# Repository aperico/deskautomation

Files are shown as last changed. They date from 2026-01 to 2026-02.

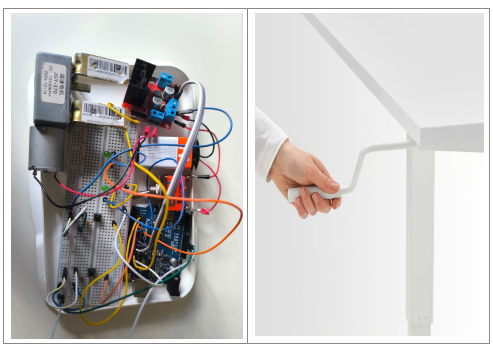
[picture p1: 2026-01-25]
00_training_context/resources/desk-arduino.png

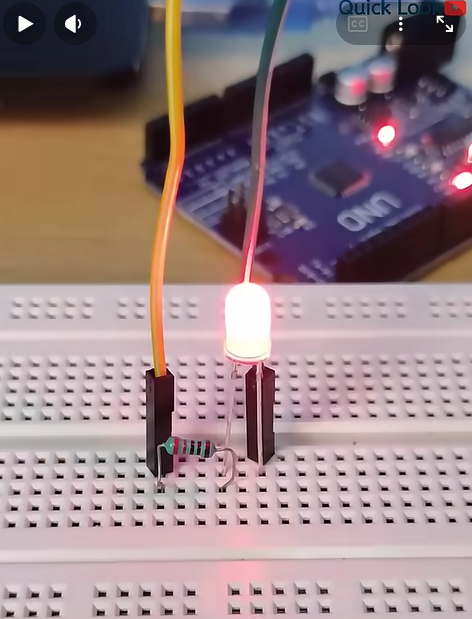
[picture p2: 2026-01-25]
00_training_context/resources/led-blink.png

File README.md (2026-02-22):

# Automated Mechanical Desk Lift System

## Quick Start

### Automated Development Pipeline (Recommended)

The fastest way to build and test the project:

```bash
# Complete pipeline: build + dual motor validation + static analysis
python toolchain/run-pipeline.py all

# Build only
python toolchain/run-pipeline.py clean-build

# Run tests (validates both MT_BASIC and MT_ROBUST motor types)
python toolchain/run-pipeline.py test

# Quick unit test during development
python toolchain/run-pipeline.py unit

# Get help
python toolchain/run-pipeline.py help
```

**📖 Detailed Instructions:**
- **Pipeline Guide:** [toolchain/README.md](toolchain/README.md) - Complete pipeline manual
- **Build Guide:** [src/README.md](src/README.md) - Manual build and test instructions
- **Test Overview:** [tests/README.md](tests/README.md) - Test suite quick reference

---

## Project Overview

The Automated Mechanical Desk Lift System is a motorized solution for height-adjustable desks, enabling users to easily switch between sitting and standing positions. The system features responsive controls, safety mechanisms to prevent accidents, and reliable operation over the product lifetime. Key features include:
- **Configurable motor drivers:** Support for both L298N (cost-optimized) and IBT_2 (high-capacity) motor controllers
- Motorized height adjustment from 30 cm to 120 cm
- Support for up to 20 kg load (monitor, keyboard, etc.)
- UP/DOWN buttons for intuitive control
- Immediate halt on button release or obstruction detection
- Robust safety features including limit sensors and current sensing for jam detection
- Smooth, predictable motion for user comfort
- Designed for office environments to improve health and productivity
- Modular architecture for maintainability and future feature expansion
- Comprehensive documentation and testing to ensure quality and reliability
- Open-source hardware and software design for community collaboration and innovation

### Motor Driver Options

The system supports two motor driver configurations, selectable at compile-time:

| Driver | Model | Cost | Capacity | Use Case |
|---|---|---|---|---|
| **MT_BASIC** | L298N Dual H-Bridge | Low (~$2-5) | Standard (~50kg) | Cost-optimized office desks |
| **MT_ROBUST** | IBT_2 Intelligent Driver | Moderate (~$10-15) | High (~100kg+) | Heavy-duty commercial desks |

Both drivers share the same software (unified HAL interface) and provide equivalent safety and functionality. See [Motor Driver Configuration Guide](documentation/07_MotorDriverConfiguration.md) for build and switching instructions.

## Motor Configuration Architecture

The system implements a robust motor configuration encapsulation pattern to support multiple motor driver types:

### Design Approach

- **Compile-Time Configuration (Current)**: Motor type is defined at compile-time in `src/motor_config.cpp` with validation
- **Runtime-Ready (Future)**: Architecture is prepared for NVM-based runtime configuration without code changes
- **Encapsulation Interface**: `MotorConfig_getMotorType()` function provides the sole accessor for motor configuration
- **Application Transparency**: All application logic is motor-type-agnostic; HAL layer handles driver-specific details

### Configuration Files

| File | Role | Details |
|---|---|---|
| `src/motor_config.h` | Public interface | Type definitions, feature documentation, function declaration |
| `src/motor_config.cpp` | Private implementation | MOTOR_TYPE macro, validation, getter function, NVM migration comments |

### Switching Motor Drivers

```bash
# Default: MT_BASIC (L298N)
cmake -S . -B build && cmake --build build

# To use MT_ROBUST (IBT_2): Edit src/motor_config.cpp line 44
# #define MOTOR_TYPE MT_BASIC        <- Change to MT_ROBUST
# Then rebuild:
cmake --build build
```

### Test Coverage

All 37 unit and integration tests validate both motor configurations:
- **MT_BASIC**: L298N driver (default)
- **MT_ROBUST**: IBT_2 driver

Tests can be run against either driver by changing the MOTOR_TYPE definition. See [05_SoftwareArchitecture.md](documentation/05_SoftwareArchitecture.md) (AD-009: Motor Configuration Encapsulation) and [06_00_DetailedDesign.md](documentation/06_00_DetailedDesign.md) (Motor Configuration Module) for detailed technical documentation.

---

## Documentation Index

### Development Guidelines

| Document | Description |
|---|---|
| [toolchain/coding_guides_and_checks.md](toolchain/coding_guides_and_checks.md) | **⚠️ Coding standards for safety-critical code (NASA Power of Ten, MISRA C:2012, ISO 25119)** |
| [toolchain/README.md](toolchain/README.md) | Development pipeline and automated testing guide |
| [toolchain/ARCHITECTURE.md](toolchain/ARCHITECTURE.md) | Pipeline architecture and design details |

### Requirements and Design

| Document | Description |
|---|---|
| [01_MissionStatement.md](documentation/01_MissionStatement.md) | Project mission and overall purpose |
| [01_SystemObjectives.md](documentation/01_SystemObjectives.md) | High-level system objectives and goals |
| [02_ConceptOfOperations.md](documentation/02_ConceptOfOperations.md) | Operational concept and use cases |
| [02_01_HARA-prep.md](documentation/02_01_HARA-prep.md) | HARA preparation (draft) |
| [02_02_HARA-complete.md](documentation/02_02_HARA-complete.md) | Hazard analysis and risk assessment (HARA) |
| [02_03_SafetyGoals.md](documentation/02_03_SafetyGoals.md) | Safety goals derived from HARA |
| [03_00_SystemRequirements.md](documentation/03_00_SystemRequirements.md) | System-level requirements specification |
| [03_01_SystemArchitecture.md](documentation/03_01_SystemArchitecture.md) | System architecture and interfaces |
| [03_01_01_TechnicalSafetyConcept.md](documentation/03_01_01_TechnicalSafetyConcept.md) | Technical safety concept |
| [03_02_RequirementsTraceabilityMatrix.md](documentation/03_02_RequirementsTraceabilityMatrix.md) | Requirements traceability matrix |
| [04_SoftwareRequirements.md](documentation/04_SoftwareRequirements.md) | Software requirements and functional specifications |
| [04_01_SoftwareVerificationSpecification.md](documentation/04_01_SoftwareVerificationSpecification.md) | Software test specifications and verification methods |
| [05_SoftwareArchitecture.md](documentation/05_SoftwareArchitecture.md) | Software architecture design and component structure |
| [06_00_DetailedDesign.md](documentation/06_00_DetailedDesign.md) | Detailed software design and implementation details |
| [06_01_DetailedDesign_InteractionDiagrams.md](documentation/06_01_DetailedDesign_InteractionDiagrams.md) | Sequence diagrams and data flow visualizations |
| [07_MotorDriverConfiguration.md](documentation/07_MotorDriverConfiguration.md) | Motor driver configuration guide (L298N vs IBT_2)
| [10_SystemTestSpecification.md](documentation/10_SystemTestSpecification.md) | System test plan and test specifications |
| [10_01_SystemTestReport.md](documentation/10_01_SystemTestReport.md) | System test report and results |
| [11_HardwareDocumentation.md](documentation/11_HardwareDocumentation.md) | Hardware components and wiring documentation |
| [02_ConceptOfOperations_Reviews.md](documentation/02_ConceptOfOperations_Reviews.md) | ConOps review protocol and records |
| [03_00_SystemRequirements_Reviews.md](documentation/03_00_SystemRequirements_Reviews.md) | System requirements review protocol and records |
| [03_01_01_TechnicalSafetyConcept_Reviews.md](documentation/03_01_01_TechnicalSafetyConcept_Reviews.md) | Technical safety concept review protocol and records |
| [03_01_SystemArchitecture_Reviews.md](documentation/03_01_SystemArchitecture_Reviews.md) | System architecture review protocol and records |
| [04_SoftwareRequirements_Reviews.md](documentation/04_SoftwareRequirements_Reviews.md) | Software requirements review protocol and records |
| [05_SoftwareArchitecture_Reviews.md](documentation/05_SoftwareArchitecture_Reviews.md) | Software architecture review protocol and records |
| [06_DetailedDesign_Reviews.md](documentation/06_DetailedDesign_Reviews.md) | Detailed design review protocol and records |
| [10_SystemTestSpecification_Reviews.md](documentation/10_SystemTestSpecification_Reviews.md) | System test specification review protocol and records |
| [feature-pdrs/](documentation/feature-pdrs/) | System feature concept reviews |

## Project Structure

### Root Directory

| File/Directory | Description |
|---|---|
| `CMakeLists.txt` | CMake build configuration file |
| `CMakePresets.json` | CMake preset configurations |
| `README.md` | Project overview and instructions (this file) |
| `.github/` | GitHub workflows and CI/CD configuration |

### Source Code (`src/`)

| File | Description |
|---|---|
| `desk_app.cpp/h` | Main application logic and state machine |
| `desk_types.h` | Type definitions and data structures |
| `hal.cpp/h` | Hardware Abstraction Layer (HAL) interface |
| `motor_config.h` | Motor driver type configuration (MT_BASIC or MT_ROBUST) |
| `motor_controller.cpp/h` | Motor control logic and algorithms |
| `pin_config.h` | Arduino pin assignments (configurable per motor type) |
| `src.ino` | Arduino firmware entry point |

### Tests (`tests/`)

| File | Description |
|---|---|
| `UnitTests.cpp` | Unit tests for individual functions and classes |
| `ComponentTests.cpp` | Component-level integration tests |
| `IntegrationTests.cpp` | Full system integration tests |
| `hal_mock/` | Mock implementations of HAL for testing on host |
| `└── HALMock.cpp/h` | Mock HAL implementation |
| `└── SerialMock.cpp/h` | Mock Serial communication for testing |

### Training Materials (`00_training_context/`)

| File | Description |
|---|---|
| `00_agenda.md` | Training overview and agenda |
| `01_hello-world.md` | Getting started guide |
| `02_aisetup.md` | AI/Copilot setup instructions |
| `03_prompting-techniques.md` | AI prompting best practices |
| `04_00_deskautomation-syseng.md` | Systems engineering overview |
| `04_01_00_system-definition.md` | System definition guide |
| `04_01_01_system-definition-architecture.md` | Architecture definition guide |
| `04_02_software-construction.md` | Software construction practices |
| `04_03_00_component-verification.md` | Component testing guide |
| `04_03_01_software_integration-verification.md` | Integration testing guide |
| `04_03_03_system-testing.md` | System testing guide |
| `05_traceability-matrix.md` | Requirements traceability |
| `06_workflow-pipelines.md` | CI/CD pipeline documentation |
| `07_process-assessment.md` | Process quality assessment |

### Schematics (`schematics/`)

| Directory | Description |
|---|---|
| `schmatics_desk_automation/` | KiCad project files for desk automation |
| `└── DeskAutomation_MotorControl/` | Motor control circuit schematics |
| `└── DeskAutomation.pretty/` | Custom KiCad footprints |

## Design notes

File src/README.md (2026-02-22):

# Source Code Build & Test Guide

This directory contains the source code for the Automated Mechanical Desk Lift System. For high-level project documentation and overview, see the [main README](../README.md).

## 🚀 Recommended: Automated Pipeline

**Use the automated development pipeline for the fastest and most reliable builds:**

```bash
# Complete pipeline: build + dual motor validation + static analysis
python toolchain/run-pipeline.py all

# Build only (clean + configure + build)
python toolchain/run-pipeline.py clean-build

# Run all tests (validates both MT_BASIC and MT_ROBUST motor types)
python toolchain/run-pipeline.py test

# Quick development workflow
python toolchain/run-pipeline.py unit        # Unit tests only
python toolchain/run-pipeline.py component   # Component tests only

# Get help
python toolchain/run-pipeline.py help
```

**Why use the pipeline?**
- ✅ Automated dual motor type validation (MT_BASIC + MT_ROBUST)
- ✅ Consistent build environment
- ✅ Comprehensive test coverage (37 tests)
- ✅ Static analysis integration
- ✅ Detailed results saved to `toolchain/results/`

**📖 Complete Pipeline Documentation:** [toolchain/README.md](../toolchain/README.md)

---

## Manual Build Instructions

For manual control or understanding the build process, use these commands:

### Prerequisites
- Windows with MSYS2 installed
- CMake
- MinGW-w64 toolchain (via MSYS2)
- C++17 compiler

### Build Commands (Command Line)

#### Clean Build Directory
```bash
Remove-Item -Path "build" -Recurse -Force -ErrorAction SilentlyContinue
```

Or using CMake:
```bash
cmake --build build --target clean
```

#### Configure
```bash
cmake -S . -B build
```

**With Motor Driver Selection:**
```bash
# Build for L298N (default)
cmake -S . -B build -DMOTOR_TYPE=MT_BASIC

# Build for IBT_2 (high-capacity)
cmake -S . -B build -DMOTOR_TYPE=MT_ROBUST
```

#### Build
```bash
cmake --build build --config Release
```

#### Full Build Sequence (Clean → Configure → Build)
```bash
Remove-Item -Path "build" -Recurse -Force -ErrorAction SilentlyContinue
cmake -S . -B build
cmake --build build --config Release
```

### Build Using VS Code Tasks

The project includes predefined VS Code tasks for building:

1. **CMake: Clean** - Removes the build directory
2. **CMake: Configure** - Configures the CMake project (depends on Clean)
3. **CMake: Build** - Builds the project (depends on Configure)

To run these tasks:
- Press `Ctrl+Shift+P` and type "Run Task"
- Select the desired task from the list
- Or use the Terminal menu → Run Task

The tasks automatically chain dependencies, so running "CMake: Build" will clean and configure first if needed.

### Build Artifacts

After a successful build, you'll find:
- `build/UnitTests.exe` - Unit test executable (6 tests)
- `build/ComponentTests.exe` - Component test executable (17 tests)
- `build/IntegrationTests.exe` - Integration test executable (14 tests)
- Build artifacts in `build/` directory

## Motor Driver Configuration

The system supports two motor driver configurations selected at compile-time:

| Driver | Model | Capacity | Use Case |
|---|---|---|---|
| **MT_BASIC** (default) | L298N Dual H-Bridge | Standard (~50kg) | Cost-optimized office desks |
| **MT_ROBUST** | IBT_2 Intelligent Driver | High (~100kg+) | Heavy-duty commercial desks |

Both drivers share the same software architecture and provide identical safety functionality through a unified Hardware Abstraction Layer (HAL).

### Selecting a Motor Driver

**Option 1: CMake Configuration (Recommended)**

When configuring the build, specify the motor type:

```bash
# Build for L298N (default) - cost-optimized
cmake -S . -B build -DMOTOR_TYPE=MT_BASIC
cmake --build build --config Release

# Build for IBT_2 - high-capacity
cmake -S . -B build -DMOTOR_TYPE=MT_ROBUST
cmake --build build --config Release
```

**Option 2: Edit motor_config.h**

Edit [motor_config.h](motor_config.h) line 47:

```cpp
// For L298N:
#define MOTOR_TYPE MT_BASIC      // Default

// For IBT_2:
#define MOTOR_TYPE MT_ROBUST
```

Then clean and rebuild:
```bash
Remove-Item -Path build -Recurse -Force
cmake -S . -B build
cmake --build build --config Release
```

### Verifying Motor Driver Type

After building, the active motor driver type is embedded in the binary. Pin assignments are determined by the selection:

**L298N (MT_BASIC):**
- PIN_MOTOR_EN1 = 6  (Enable UP direction)
- PIN_MOTOR_EN2 = 7  (Enable DOWN direction)
- PIN_MOTOR_PWM = 9  (Speed control)

**IBT_2 (MT_ROBUST):**
- PIN_MOTOR_LPWM = 9   (Left PWM - UP direction)
- PIN_MOTOR_RPWM = 10  (Right PWM - DOWN direction)
- PIN_MOTOR_CIN = A1   (Diagnostic input, optional)

See [Motor Driver Configuration Guide](../documentation/07_MotorDriverConfiguration.md) for detailed hardware setup instructions.

## Configuration

Safety-related thresholds and ADC conversion constants are defined in [safety_config.h](safety_config.h).

```cpp
static const uint16_t MOTOR_SENSE_THRESHOLD_MA = 150U;
static const uint16_t MOTOR_SENSE_OBSTRUCTION_THRESHOLD_MA = 200U;
static const uint32_t MOTOR_SENSE_FAULT_TIME_MS = 100U;
static const uint16_t ADC_REF_MV = 5000U;
static const uint16_t SHUNT_MILLIOHMS = 500U;
```

**Tuning guidance:**
- Measure motor current at idle STOP and normal motion with a meter.
- Set `MOTOR_SENSE_THRESHOLD_MA` above STOP current noise but below expected motion current.
- Set `MOTOR_SENSE_OBSTRUCTION_THRESHOLD_MA` to detect jam conditions during motion (typically 200 mA).
- Verify `MOTOR_SENSE_FAULT_TIME_MS` avoids false positives during brief transients.
- If you change the shunt resistor, update `SHUNT_MILLIOHMS` to keep current conversion accurate.

## Testing

### Building Tests

Tests are automatically built as part of the main build process. The CMake configuration includes all test files and links them with Google Test.

To build tests:
```bash
# Full build (includes tests)
cmake -S . -B build
cmake --build build --config Release
```

Or use the VS Code task: **CMake: Build**

### Test Executables

After building, the test executables are located at:
```
build/UnitTests.exe        - Unit tests (6 tests)
build/ComponentTests.exe   - Component tests (17 tests)
build/IntegrationTests.exe - Integration tests (14 tests)
Total: 37 tests
```

### Running Tests

#### Run All Tests

Using CTest (runs all test executables):
```bash
ctest --test-dir build -C Release --output-on-failure
```

Using test executables directly:
```bash
# Run all unit tests
./build/UnitTests.exe

# Run all component tests
./build/ComponentTests.exe

# Run all integration tests
./build/IntegrationTests.exe
```

Or use the VS Code task: **CTest: Run All**

#### Run Specific Tests

Run specific unit tests:
```bash
./build/UnitTests.exe --gtest_filter=MotorController.*
```

Run specific component tests:
```bash
./build/ComponentTests.exe --gtest_filter=TC_SWReq001
```

Run specific integration tests:
```bash
./build/IntegrationTests.exe --gtest_filter=HAL.*
```

Using CTest with regex filter:
```bash
ctest --test-dir build -C Release -R "^ComponentTests$" --output-on-failure
```

#### List Available Tests

```bash
# List unit tests
./build/UnitTests.exe --gtest_list_tests

# List component tests
./build/ComponentTests.exe --gtest_list_tests

# List integration tests
./build/IntegrationTests.exe --gtest_list_tests
```

### Test Types

The project includes three types of tests:

1. **Unit Tests** - Test individual functions and classes in isolation
2. **Component Tests** - Test integrated components (e.g., DeskController with mocked HAL)
3. **Integration Tests** - Test full system integration with hardware abstraction layer

All tests use Google Test framework and are located in the `tests/` directory.

### Test Filtering Options

Google Test supports various filtering patterns:
- `*` - Matches any string
- `?` - Matches any single character
- Use `:` to separate multiple patterns (OR logic)
- Prefix with `-` to exclude tests

Examples:
```bash
# Run all tests in a component test suite except one
./build/ComponentTests.exe --gtest_filter=-TC_SWReq001

# Run multiple specific unit tests
./build/UnitTests.exe --gtest_filter=MotorController.Initialize:MotorController.SetSpeed
```

## CI/CD Pipeline

### Local Development Pipeline

The `tests/toolchain/run-pipeline.py` script provides a convenient way for developers to execute common development tasks locally, including building, testing, and static analysis.

#### Prerequisites

- Python 3.7+
- MSYS2 with MinGW-w64 toolchain
- CMake
- cppcheck (for static analysis): `pacman -S mingw-w64-x86_64-cppcheck`

#### Usage

```bash
python tests/toolchain/run-pipeline.py <command>
```

#### Available Pipeline Commands

| Command | Description |
|---|---|
| `clean-build` | Clean build directory and build the project |
| `rebuild` | Full rebuild (clean + configure + build) |
| `test` | Run all test cases |
| `clean-test` | Clean, build, and run all test cases |
| `static-analysis` | Run static analysis using cppcheck |
| `all` | Run everything (rebuild + test + static analysis) |
| `help` | Show help message |

#### Pipeline Examples

**Clean and Build:**
```bash
python tests/toolchain/run-pipeline.py clean-build
```

**Rebuild Everything:**
```bash
python tests/toolchain/run-pipeline.py rebuild
```

**Run All Tests:**
```bash
python tests/toolchain/run-pipeline.py test
```

**Clean and Run All Tests:**
```bash
python tests/toolchain/run-pipeline.py clean-test
```

**Run Static Analysis:**
```bash
python tests/toolchain/run-pipeline.py static-analysis
```

**Run Complete Pipeline:**
```bash
python tests/toolchain/run-pipeline.py all
```

This will:
1. Clean the build directory
2. Configure CMake
3. Build the project
4. Run all tests
5. Run static analysis

#### Pipeline Output

The script provides color-coded output:
- 🟢 Green: Success messages
- 🔵 Cyan: Info messages
- 🔴 Red: Error messages
- 🟡 Yellow: Section headers

#### Pipeline Results Storage

All pipeline results are stored in the `tests/results/` directory:

| Result File | Description |
|---|---|
| `cmake_configure.txt` | CMake configuration output with warnings |
| `build_log.txt` | Complete build log with compiler warnings |
| `test_results.txt` | Test execution results with pass/fail summary |
| `static_analysis.txt` | Human-readable static analysis report |
| `static_analysis.xml` | Machine-readable XML for CI integration |

**Note:** Result files are overwritten on each pipeline run. Each file includes a header with:
- Full command executed
- Timestamp of execution
- Brief description of the results
- Relevant configuration details

These logs are useful for:
- Reviewing the latest build/test/analysis results
- Debugging compilation issues
- Quick access to compiler warnings and static analysis findings
- CI integration via XML output

#### Pipeline Exit Codes

- `0`: Success
- `1`: Failure (build, test, or analysis failed)

#### Local vs CI/CD

This script mirrors the CI/CD pipeline configured in `.github/workflows/`, allowing developers to validate their changes locally before pushing to the repository.

## Source Files

| File | Description |
|---|---|
| `desk_app.cpp/h` | Main application logic and state machine |
| `desk_types.h` | Type definitions and data structures |
| `hal.cpp/h` | Hardware Abstraction Layer (HAL) interface |
| `motor_controller.cpp/h` | Motor control logic and algorithms |
| `pin_config.h` | Arduino pin assignments and hardware configuration |
| `safety_config.h` | Safety thresholds and configuration constants |
| `src.ino` | Arduino firmware entry point |

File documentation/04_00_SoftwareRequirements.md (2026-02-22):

# Software Requirements

## Overview

This document defines functional software requirements derived from system requirements. These requirements specify **what** the software subsystem shall do, independent of hardware implementation. All requirements are designed to be unit-testable using mock hardware abstractions.

**Document Version:** 1.1  
**Date:** January 25, 2026  
**Status:** Updated

---

## Abstraction Layer

Software requirements are intentionally **hardware-independent**:

- ❌ No pin numbers or GPIO addresses
- ❌ No motor driver chip specifications
- ❌ No PWM frequency or duty cycle details
- ✅ Focus on software logic, timing, and state management
- ✅ Hardware abstraction layer (HAL) isolates physical interface

**Hardware dependencies are encapsulated in HAL**, which provides:
- `HAL_readButton(button_id)` → button state
- `HAL_readLimitSensor(sensor_id)` → sensor state
- `HAL_setMotor(direction, speed)` → motor control
- `HAL_getTime()` → system time in ms

## Requirements Characteristics

All software requirements comply with INCOSE quality criteria:

- ✅ **Necessary**: Each requirement addresses a distinct software function
- ✅ **Unambiguous**: Uses "shall" with quantitative acceptance criteria
- ✅ **Verifiable**: Unit test methods specified using mocks/stubs
- ✅ **Feasible**: All requirements implementable in embedded software
- ✅ **Traceable**: Clear links to parent system requirements
- ✅ **Software-focused**: Describes software behavior, not hardware implementation

## Traceability

**Derived from:**
- [03_00_SystemRequirements.md](03_00_SystemRequirements.md)

**Verification:**
- [04_01_SoftwareVerificationSpecification.md](04_01_SoftwareVerificationSpecification.md)

---

## Requirements Specification

| SWReq-ID | Statement | Rationale | Derives From |
|---|---|---|---|
| **SWReq-001** | The software subsystem shall detect UP button press within 100 ms and command motor activation in the upward direction. | Supports system responsiveness requirement (SysReq-002). Software input processing latency must be minimized to meet 1.0 sec total response budget. | SysReq-002 |
| **SWReq-002** | The software subsystem shall detect DOWN button press within 100 ms and command motor activation in the downward direction. | Supports system responsiveness requirement (SysReq-002). Software input processing latency must be minimized to meet 1.0 sec total response budget. | SysReq-002 |
| **SWReq-003** | The software subsystem shall detect button release within 50 ms and command motor deactivation. | Critical for meeting 500 ms halt requirement (SysReq-003). Software must respond faster than system-level budget to account for hardware response time. | SysReq-003 |
| **SWReq-004** | The software subsystem shall ignore motor activation commands when both UP and DOWN buttons are detected as pressed simultaneously. | Implements safety logic for conflicting inputs (SysReq-005). Prevents undefined motor behavior and potential hardware stress. | SysReq-005 |
| **SWReq-005** | The software subsystem shall command motor stop when upper limit sensor is active, even if UP button is pressed. | Enforces travel limit protection (SysReq-007). Software must override user input to protect mechanical system. | SysReq-007 |
| **SWReq-006** | The software subsystem shall command motor stop when lower limit sensor is active, even if DOWN button is pressed. | Enforces travel limit protection (SysReq-007). Software must override user input to protect mechanical system. | SysReq-007 |
| **SWReq-007** | The software subsystem shall maintain motor control state machine with at least three states: IDLE, MOVING_UP, and MOVING_DOWN. | Provides structured control logic for predictable behavior (SysReq-002, SysReq-003). State machine ensures unambiguous system response to all input combinations. | SysReq-002, SysReq-003 |
| **SWReq-008** | The software subsystem shall execute the main control loop with a cycle time of ≤ 50 ms. | Ensures timely input processing and output response to meet system timing requirements (SysReq-002, SysReq-003). Fast loop enables responsive button detection and motor commands. | SysReq-002, SysReq-003 |
| **SWReq-009** | The software subsystem shall debounce button inputs using a 20 ms debounce window. | Prevents false triggers from mechanical button bounce, ensuring reliable user intent detection (SysReq-002). Industry-standard debounce time for tactile switches. | SysReq-002 |
| **SWReq-010** | The software subsystem shall maintain operational state and command history for diagnostic purposes. | Supports reliability and maintainability goals (SysReq-008). Enables post-failure analysis and verification of state transitions during testing. | SysReq-008 |
| **SWReq-011** | The software subsystem shall implement a non-blocking scheduler that invokes `APP_Task()` at a fixed period of 250 ms (±10 ms). | Provides deterministic application-level timing while avoiding blocking calls in the main loop, enabling timely safety reactions and I/O servicing. | SysReq-009 |
| **SWReq-012** | The software subsystem shall command motor STOP when no valid UP/DOWN command is present. | Prevents unintended motion in the absence of user intent (SysReq-010). | SysReq-010 |
| **SWReq-013** | The software subsystem shall initialize to a safe STOP state after reset or brownout and require a new valid command before motion. | Prevents unintended motion on power recovery (SysReq-011). | SysReq-011 |
| **SWReq-014** | The software subsystem shall detect motor driver stuck-on or runaway behavior and enter a fault state that commands STOP and indicates error. | Mitigates electrical fault hazards (SysReq-012). | SysReq-012 |
| **SWReq-015** | The software subsystem shall support configurable motor driver implementation (MT_BASIC: L298N or MT_ROBUST: IBT_2) with identical functional behavior across both variants. | Enables product line support for multiple hardware configurations from unified codebase (SysReq-014). All control logic, safety features, and timing requirements shall be motor-type-agnostic; differences encapsulated in HAL. | SysReq-014 |

---

## Requirements Traceability Matrix

### Upstream Traceability (System → Software)

| System Requirement | Derived Software Requirements |
|---|---|
| SysReq-002: Response Time | SWReq-001, SWReq-002, SWReq-007, SWReq-008, SWReq-009 |
| SysReq-003: Motion Halt | SWReq-003, SWReq-007, SWReq-008 |
| SysReq-005: Conflicting Inputs | SWReq-004 |
| SysReq-007: Limit Protection | SWReq-005, SWReq-006 |
| SysReq-008: Reliability | SWReq-010 |
| SysReq-009: Scheduler Cadence | SWReq-011, SWReq-008 |
| SysReq-010: No Motion Without Valid Command | SWReq-012 |
| SysReq-011: Safe STOP After Reset/Brownout | SWReq-013 |
| SysReq-012: Stuck-On/Runaway Detection | SWReq-014 |
| SysReq-014: Motor Type Configuration | SWReq-015 |

---

## Test Strategy

All software verification specifications, test methods, test procedures, and test coverage requirements are defined in [04_01_SoftwareVerificationSpecification.md](04_01_SoftwareVerificationSpecification.md).

---

## Software Requirements Allocation

| Software Component | Allocated Requirements |
|---|---|
| Button Input Handler | SWReq-001, SWReq-002, SWReq-003, SWReq-009 |
| State Machine | SWReq-007, SWReq-010 |
| Safety Logic | SWReq-004, SWReq-005, SWReq-006, SWReq-012 |
| Control Loop Manager | SWReq-008 |
| Startup/Reset Handling | SWReq-013 |
| Fault Handling/Diagnostics | SWReq-014 |
| Motor Configuration Module | SWReq-015 |

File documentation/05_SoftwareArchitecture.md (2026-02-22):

# Software Architecture

## Overview

This document defines the software architecture for the Standing Desk Automation System. The architecture follows a layered design pattern with clear separation of concerns to enable testability, maintainability, and safety.

**Document Purpose and Detail Level**
- **Purpose:** Define the software structure, responsibilities, and interfaces needed to implement the system requirements.
- **Detail Level:** Software layers, modules, data flow, and state machine behavior; no system hardware decomposition.
- **Use:** Input to detailed design and test development; aligns with system architecture constraints.

**Document Version:** 1.0  
**Date:** January 24, 2026  
**Status:** Approved

---

## Traceability

**Derived from:**
- [03_00_SystemRequirements.md](03_00_SystemRequirements.md)
- [03_01_SystemArchitecture.md](03_01_SystemArchitecture.md)
- [04_SoftwareRequirements.md](04_SoftwareRequirements.md)

---

## Architectural Principles

1. **Testability**: Application logic is hardware-independent and unit-testable with mocks
2. **Simplicity**: Suitable for resource-constrained Arduino environment
3. **Safety**: State machine enforces safety rules and deterministic behavior
4. **Real-time**: Software design meets system-level timing constraints

---

## Timing and Safety Constraints

System-level timing and safety requirements are defined in the System Architecture and Technical Safety Concept. The software design implements these constraints via the control loop, state machine, and safety logic.

---

## Layer Architecture

```mermaid
graph TB
    subgraph "Layer 4: Main Loop / Signal Layer"
        Main[Main Loop<br/>arduino.ino]
    end
    
    subgraph "Layer 3: Application Layer"
        App[DeskApp<br/>DeskController.cpp/h]
    end
    
    subgraph "Layer 2: Hardware Abstraction Layer"
        HAL[HAL Module<br/>HAL.cpp/h]
    end
    
    subgraph "Layer 1: Hardware"
        HW[Physical Hardware<br/>GPIO, PWM, Timers]
    end
    
    Main -->|APP_Task| App
    App -->|Motor Commands| Main
    Main -->|HAL_read/write| HAL
    HAL -->|digitalWrite, analogWrite| HW
    
    style Main fill:#FFE6CC
    style App fill:#90EE90
    style HAL fill:#87CEEB
    style HW fill:#FFE6E6
```

### Layer 1: Hardware (External)

**Responsibility:** Provide physical inputs/outputs to the software via GPIO, PWM, and ADC signals.

**Description:** Hardware composition and wiring are defined at the system level; see System Architecture for component details.

---

### Layer 2: Hardware Abstraction Layer (HAL)

**Responsibility:** Encapsulate all hardware-specific code; provide hardware-independent API to upper layers.

**Files:** `HAL.h`, `HAL.cpp`, `PinConfig.h`

**Key Interfaces:** Hardware I/O functions for buttons, limits, motor, LEDs, and time services. Detailed signatures and data types are defined in the Detailed Design Specification.

**Description:** HAL is the only layer with direct access to Arduino libraries (digitalWrite, analogWrite, millis). Pin assignments and concrete data types are specified in the Detailed Design.

---

### Layer 3: Application Layer (DeskApp)

**Responsibility:** Implement desk control logic, state machine, and safety rules; hardware-agnostic.

**File:** `DeskController.h`, `DeskController.cpp`

**Description:** DeskApp contains the state machine and business logic. It is fully testable with mock inputs/outputs.

**Interfaces:** Function signatures and data structures are defined in the Detailed Design Specification.

---

### Layer 4: Main Loop / Signal Layer

**Responsibility:** Poll hardware via HAL, populate input structure, call APP_Task, execute output commands.

**File:** `arduino.ino`

**Description:** Main loop orchestrates I/O coordination and schedules the application task. Implementation details are specified in the Detailed Design.

---

## Motor Driver Abstraction

### Supported Drivers

The software architecture supports multiple motor driver implementations transparent to application logic:

| Driver | Model | Capabilities | Status |
|---|---|---|---|
| **MT_BASIC** | L298N Dual H-Bridge | Standard H-bridge with PWM speed control | ✅ Supported |
| **MT_ROBUST** | IBT_2 Dual H-Bridge (FET) | Enhanced H-bridge with better thermal characteristics | ✅ Supported |

### Abstraction Strategy

**Motor-Type-Agnostic Application Logic:**
- Application layer (`DeskApp`) makes no assumptions about hardware capabilities
- All control logic, safety features, and timing constraints are identical for both drivers
- Motor type influences only HAL implementation details, not functional behavior

**HAL Motor Control Interface:**
```
HAL_setMotor(direction, speed)  // Same interface for both drivers
├── MT_BASIC: Drives L298N GPIO pins (standard H-bridge)
└── MT_ROBUST: Drives IBT_2 GPIO pins (enhanced FET driver)
```

**Current Sensing Abstraction:**
```
current_ma = HAL_readMotorCurrent()  // Same interface for both drivers
├── MT_BASIC: Always returns 0 (no current sensor in hardware)
└── MT_ROBUST: Returns actual current from sense resistor
```

### Configuration Selection

Motor type is selected at compile-time via `motor_config.cpp`:
```cpp
#define MOTOR_TYPE MT_BASIC  // Change to MT_ROBUST for IBT_2 driver
```

All 37 unit and integration tests verify identical behavior across both configurations:
- Tests execute with default MT_BASIC configuration
- Can be recompiled with `TEST_MOTOR_TYPE=MT_ROBUST` to validate IBT_2 without code changes
- Both configurations pass all verification specifications without functional differences

---

## State Machine Design

### State Diagram

```mermaid
stateDiagram-v2
    [*] --> IDLE: Power On / APP_Init()
    
    IDLE --> MOVING_UP: UP pressed AND NOT upper_limit
    IDLE --> MOVING_DOWN: DOWN pressed AND NOT lower_limit
    IDLE --> IDLE: Both buttons pressed (conflicting input)
    
    MOVING_UP --> IDLE: UP released
    MOVING_UP --> IDLE: upper_limit reached
    MOVING_UP --> FAULT: Unexpected error
    
    MOVING_DOWN --> IDLE: DOWN released
    MOVING_DOWN --> IDLE: lower_limit reached
    MOVING_DOWN --> FAULT: Unexpected error
    
    FAULT --> IDLE: Fault cleared (power cycle)
    
    note right of IDLE
        Motor: STOP
        LED: IDLE (steady green)
    end note
    
    note right of MOVING_UP
        Motor: UP (speed 255)
        LED: ACTIVE (blinking)
    end note
    
    note right of MOVING_DOWN
        Motor: DOWN (speed 255)
        LED: ACTIVE (blinking)
    end note
    
    note right of FAULT
        Motor: STOP
        LED: ERROR (steady red)
    end note
```

### State Transition Table

| Current State | Input Condition | Next State | Motor Command | LED Status |
|---|---|---|---|---|
| IDLE | UP pressed AND NOT upper_limit | MOVING_UP | UP, speed=255 | ACTIVE |
| IDLE | DOWN pressed AND NOT lower_limit | MOVING_DOWN | DOWN, speed=255 | ACTIVE |
| IDLE | Both buttons pressed | IDLE | STOP | IDLE |
| IDLE | No buttons pressed | IDLE | STOP | IDLE |
| MOVING_UP | UP still pressed AND NOT upper_limit | MOVING_UP | UP, speed=255 | ACTIVE |
| MOVING_UP | UP released | IDLE | STOP | IDLE |
| MOVING_UP | upper_limit reached | IDLE | STOP | IDLE |
| MOVING_DOWN | DOWN still pressed AND NOT lower_limit | MOVING_DOWN | DOWN, speed=255 | ACTIVE |
| MOVING_DOWN | DOWN released | IDLE | STOP | IDLE |
| MOVING_DOWN | lower_limit reached | IDLE | STOP | IDLE |
| Any State | Unexpected error | FAULT | STOP | ERROR |

### State Entry/Exit Actions

**IDLE State:**
- **Entry:** Motor STOP, LED IDLE
- **In-State:** Monitor button inputs
- **Exit:** None

**MOVING_UP State:**
- **Entry:** Motor UP (speed=255), LED ACTIVE
- **In-State:** Monitor button release and upper limit
- **Exit:** Motor STOP

**MOVING_DOWN State:**
- **Entry:** Motor DOWN (speed=255), LED ACTIVE
- **In-State:** Monitor button release and lower limit
- **Exit:** Motor STOP

**FAULT State:**
- **Entry:** Motor STOP, LED ERROR, log fault
- **In-State:** System halted
- **Exit:** Requires power cycle to clear

---

## Interaction Diagrams

Interaction sequences and data flow diagrams are maintained in the Detailed Design Specification to keep implementation-level behavior in a single location.

---

## Requirements Traceability Matrix

### System Requirements → Architecture Elements

| System Req | Software Req | Architecture Element | Layer | Verification |
|---|---|---|---|---|
| SysReq-001 | SWReq-005, SWReq-006 | Limit sensor input + Safety logic | APP, HAL | Unit test with mock sensors |
| SysReq-002 | SWReq-001, SWReq-002, SWReq-008 | Button input handler + State transitions | APP, HAL | Timing test with mock GPIO |
| SysReq-003 | SWReq-003 | Button release detection + Motor stop | APP, HAL | Unit test with mock timer |
| SysReq-004 | SWReq-008 | Control loop timing (≤50ms cycle) | Main Loop | Loop timing measurement |
| SysReq-005 | SWReq-004 | Conflicting input detection | APP | Unit test with both buttons |
| SysReq-006 | — | Motor speed control (constant 255) | HAL | (Future: PWM ramping) |
| SysReq-007 | SWReq-005, SWReq-006 | Limit override logic | APP | Unit test with limit active |
| SysReq-008 | SWReq-010 | State transition logging | APP | Diagnostic log verification |

### Software Requirements → Architecture Functions

| Software Req | Function/Module | API | Layer |
|---|---|-----|---|
| SWReq-001 | Button UP handler | `HAL_readButton(BUTTON_UP)` | HAL |
| SWReq-002 | Button DOWN handler | `HAL_readButton(BUTTON_DOWN)` | HAL |
| SWReq-003 | Button release handler | `HAL_readButton()` + debounce | HAL |
| SWReq-004 | Conflicting input check | Safety logic in `APP_Task()` | APP |
| SWReq-005 | Upper limit check | `HAL_readLimitSensor(LIMIT_UPPER)` | HAL |
| SWReq-006 | Lower limit check | `HAL_readLimitSensor(LIMIT_LOWER)` | HAL |
| SWReq-007 | State machine | `APP_Task()` state transitions | APP |
| SWReq-008 | Control loop | `loop()` execution | Main |
| SWReq-009 | Debouncing | `HAL_readButton()` internal logic | HAL |
| SWReq-010 | Diagnostics | `APP_GetState()`, state log | APP |

---

## Interface Specifications

Detailed interface definitions, pin assignments, and timing budgets are specified in the Detailed Design Specification.

## Architectural Decisions

### AD-001: Layered Architecture
**Decision:** Use 4-layer architecture (Hardware, HAL, APP, Main Loop).  
**Rationale:** Enables unit testing of application logic without hardware; supports future platform portability.  
**Traceability:** All software requirements (SWReq-001 through SWReq-010).

### AD-002: State Machine Pattern
**Decision:** Implement control logic as explicit state machine with 4 states.  
**Rationale:** Provides deterministic, verifiable behavior; simplifies safety analysis.  
**Traceability:** SWReq-007, SysReq-002, SysReq-003.

### AD-003: Input/Output Structures
**Decision:** Use C structures for APP_Task interface instead of individual parameters.  
**Rationale:** Simplifies unit testing; easier to extend with new signals; clear API boundary.  
**Traceability:** SWReq-001 through SWReq-006.

### AD-004: HAL Owns All Hardware Access
**Decision:** Only HAL layer calls Arduino functions (digitalWrite, analogWrite, millis).  
**Rationale:** Enables mock-based testing; single point for hardware dependencies.  
**Traceability:** All software requirements.

### AD-005: Constant Motor Speed (No Ramping)
**Decision:** Motor speed fixed at 255 (full speed); no acceleration/deceleration profile.  
**Rationale:** Simplifies initial implementation; meets system requirements; ramping can be added later.  
**Traceability:** SysReq-004, SysReq-006.

### AD-006: Debouncing in HAL
**Decision:** Button debouncing implemented inside HAL_readButton().  
**Rationale:** Isolates timing complexity from APP layer; reusable across projects.  
**Traceability:** SWReq-009.

### AD-007: Limit Sensors Override Buttons
**Decision:** Limit sensors take priority over button inputs in safety logic.  
**Rationale:** Prevents mechanical over-travel; safety-critical requirement.  
**Traceability:** SysReq-007, SWReq-005, SWReq-006.

### AD-008: Non-Blocking Main Loop with Time-Based Scheduler
**Decision:** Main loop is non-blocking and executes application control logic at 4 Hz (every 250 ms).  
**Rationale:** 
- Prevents blocking delays that can impair safety-critical button response
- 4 Hz scheduler provides predictable timing for application task invocation
- Arduino loop() is called frequently; explicit timing check prevents excessive application task calls
- Allows I/O operations (HAL calls) to complete without waiting
**Traceability:** Foundational to responsive button handling (SysReq-002: ≤1 sec response) and halt timing (SysReq-003: ≤500 ms halt).

### AD-009: Motor Configuration Encapsulation
**Decision:** Motor type configuration is encapsulated via `MotorConfig_getMotorType()` getter function; direct application code shall not use the `MOTOR_TYPE` macro.

**Rationale:** 
- **Abstraction:** Hides motor type definition details from application code
- **Testability:** Enables testing both motor configurations (MT_BASIC and MT_ROBUST) without recompilation via `TEST_MOTOR_TYPE` override
- **Future NVM Support:** Architecture is prepared for runtime motor configuration via non-volatile memory without requiring header changes
- **Safety:** Centralized control of motor type configuration reduces risk of inconsistent usage across codebase
- **Maintenance:** Single point of definition for motor type handling simplifies future hardware variants

**Current Implementation:** Compile-time configuration (default: MT_BASIC/L298N). MOTOR_TYPE macro is defined and validated in `motor_config.cpp`.

**Future Implementation:** Will read motor type from NVM at runtime, enabling hardware auto-detection and multi-configuration support without recompilation.

**Verification:** 
- Application code uses `inputs->motor_type` from AppInput struct (populated via `MotorConfig_getMotorType()`)
- HAL layer uses runtime `g_motor_type` variable (set via `HAL_setMotorType()`)
- All 37 unit and integration tests validate both MT_BASIC and MT_ROBUST configurations

**Traceability:** All software requirements (SWReq-001 through SWReq-014); ensures motor-type-agnostic application logic.

---

## Design Constraints

1. **Memory:** Arduino UNO has 2 KB SRAM; minimize global variables
2. **Timing:** 
    - Meet system-level response and halt timing constraints
    - No blocking delays in main loop; utilize non-blocking scheduler (see AD-008)
3. **Safety:** All motor commands must be fail-safe (default to STOP)
4. **Testability:** APP layer must be testable without Arduino hardware

---

## Future Enhancements (Out of Scope)

- **Runtime Motor Configuration (In Progress):** Migrate from compile-time `MOTOR_TYPE` macro to NVM-based runtime configuration, enabling hardware auto-detection without recompilation (see AD-009: Motor Configuration Encapsulation for architecture readiness)
- PWM ramping for smooth acceleration/deceleration
- Position sensing and closed-loop control
- EEPROM storage for height presets
- Serial command interface for diagnostics
- Watchdog timer for fault detection

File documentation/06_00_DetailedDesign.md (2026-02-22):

# Detailed Design Specification

## Overview

This document provides implementation-level design details for the Standing Desk Automation System. It specifies data structures, algorithms, function interfaces, timing constraints, and error handling logic required for code implementation.

---

## Traceability

**Derived from:**
- [05_SoftwareArchitecture.md](05_SoftwareArchitecture.md)
- [04_SoftwareRequirements.md](04_SoftwareRequirements.md)
- [03_00_SystemRequirements.md](03_00_SystemRequirements.md)

**Related Documents:**
- [06_01_InteractionDiagrams.md](06_01_InteractionDiagrams.md) - Sequence diagrams and data flow visualizations

---

## Document Purpose

This detailed design bridges the gap between architecture and implementation. Developers can write code directly from this specification without requiring clarification on:
- Exact data structure layouts and field types
- Algorithm implementations (debouncing, state transitions)
- Function signatures with complete parameter specifications
- Timing constraints and performance requirements
- Error handling and edge case logic

**Document Version:** 1.0  
**Date:** January 24, 2026  
**Status:** Ready for Implementation

---

## Module Structure

```mermaid
classDiagram
    class PinConfig {
        <<configuration>>
        +PIN_BUTTON_UP: uint8_t
        +PIN_BUTTON_DOWN: uint8_t
        +PIN_LIMIT_UPPER: uint8_t
        +PIN_LIMIT_LOWER: uint8_t
        +PIN_MOTOR_EN1: uint8_t
        +PIN_MOTOR_EN2: uint8_t
        +PIN_MOTOR_PWM: uint8_t
        +PIN_MOTOR_SENSE: uint8_t
        +PIN_LED_BT_UP: uint8_t
        +PIN_LED_BT_DOWN: uint8_t
        +PIN_LED_ERROR: uint8_t
    }
    
    class HAL {
        -debounce_state[]: uint32_t
        -last_button_time[]: uint32_t
        +HAL_init() void
        +HAL_readButton(ButtonID) bool
        +HAL_readLimitSensor(LimitID) bool
        +HAL_readMotorCurrent() uint16_t
        +HAL_setMotor(MotorDirection, uint8_t) void
        +HAL_setLED(LEDStatus) void
        +HAL_getTime() uint32_t
    }
    
    class DeskApp {
        -current_state: AppState_t
        -state_entry_time: uint32_t
        -transition_count: uint32_t
        +APP_Init() void
        +APP_Task(AppInput_t*, AppOutput_t*) void
        +APP_GetState() AppState_t
        -processState(AppInput_t*, AppOutput_t*) void
        -transitionTo(AppState_t) void
    }
    
    class MainLoop {
        +setup() void
        +loop() void
        -readInputs(AppInput_t*) void
        -executeOutputs(AppOutput_t*) void
    }
    
    MainLoop --> DeskApp : calls APP_Task()
    MainLoop --> HAL : calls HAL functions
    DeskApp ..> AppInput_t : uses
    DeskApp ..> AppOutput_t : produces
    HAL ..> PinConfig : uses
```

---

## Interaction Diagrams and Data Flow

Detailed sequence diagrams and data flow visualizations are provided in the standalone document [06_01_InteractionDiagrams.md](06_01_InteractionDiagrams.md). This includes:

- **Sequence 1:** Normal Desk Raise (SysReq-002, SysReq-004)
- **Sequence 2:** Emergency Halt via Button Release (SysReq-003)
- **Sequence 3:** Conflicting Button Inputs (SysReq-005, SWReq-004)
- **Sequence 4:** Upper Limit Protection (SysReq-007, SWReq-005)
- **Sequence 5:** Full System Initialization (SysReq-001, SWReq-007)
- **Data Flow Diagram:** Module interactions and data structure flow

See [06_01_InteractionDiagrams.md](06_01_InteractionDiagrams.md) for complete descriptions and timing analysis.

---

## Motor Configuration Module

### Module Purpose

The Motor Configuration module (`motor_config.h`/`.cpp`) encapsulates motor driver type selection and provides a unified interface for the rest of the software to remain motor-type-agnostic. This ensures both MT_BASIC (L298N) and MT_ROBUST (IBT_2) can be supported identically without code duplication.

### Module Interface

```cpp
/// Get the current motor driver type
/// @return MotorType_t - MT_BASIC (0u) or MT_ROBUST (1u)
MotorType_t MotorConfig_getMotorType(void);
```

### Configuration Selection

Motor type is selected via compile-time definition in `src/motor_config.cpp`:

```cpp
#define MOTOR_TYPE MT_BASIC  // Change to MT_ROBUST to use IBT_2 driver
```

When changed, rebuild required: `cmake --build build`

### Implementation Details

- **Header File** (`motor_config.h`): Contains only public interface and type definitions
  - `MotorType_t` enum (MT_BASIC=0u, MT_ROBUST=1u)
  - `MotorConfig_getMotorType()` function declaration
  - Feature comparison documentation for both drivers

- **Implementation File** (`motor_config.cpp`): Contains configuration details
  - `MOTOR_TYPE` macro definition (compile-time value)
  - Compile-time validation checks (#error on invalid values)
  - `MotorConfig_getMotorType()` implementation
  - `TEST_MOTOR_TYPE` support for test-time overrides

### Test Compatibility

The module supports dual-configuration testing:
1. **Default Build**: Compiles with MT_BASIC, all 37 tests pass on MT_BASIC
2. **Alternative Build**: Can be recompiled with `-DTEST_MOTOR_TYPE=MT_ROBUST` to validate MT_ROBUST config without code changes

All application-level tests verify identical behavior across both motor types, ensuring the motor abstraction is transparent to the rest of the system.

### Traceability

- **System Requirement**: SysReq-014 (Motor driver support)
- **Software Requirement**: SWReq-015 (Motor type configuration abstraction)
- **Architecture Decision**: AD-009 (Motor Configuration Encapsulation)

### Future Enhancement: Runtime NVM Support

The current module is designed for easy migration to runtime motor configuration:
- To enable NVM-based motor type detection, only the `motor_config.cpp` implementation needs to change
- No header changes required when adding NVM support
- All application code remains unchanged

---

## Data Structure Definitions

### 1. Enumerated Types

```cpp
// Button identifiers
typedef enum {
    BUTTON_UP = 0,
    BUTTON_DOWN = 1,
    BUTTON_COUNT = 2
} ButtonID;

// Limit sensor identifiers
typedef enum {
    LIMIT_UPPER = 0,
    LIMIT_LOWER = 1,
    LIMIT_COUNT = 2
} LimitID;

// Motor direction commands
typedef enum {
    MOTOR_STOP = 0,
    MOTOR_UP = 1,
    MOTOR_DOWN = 2
} MotorDirection;

// LED status indicators
typedef enum {
    LED_OFF = 0,      // All LEDs off
    LED_IDLE = 1,     // Steady green (system ready)
    LED_ACTIVE = 2,   // Blinking green (motion in progress)
    LED_ERROR = 3     // Steady red (fault state)
} LEDStatus;

// Application states
typedef enum {
    APP_STATE_IDLE = 0,
    APP_STATE_MOVING_UP = 1,
    APP_STATE_MOVING_DOWN = 2,
    APP_STATE_FAULT = 3,
    APP_STATE_COUNT = 4
} AppState_t;
```

### 2. Input/Output Structures

```cpp
// Application input structure (from Main Loop → APP)
typedef struct {
    bool button_up;          // True if UP button currently pressed (debounced)
    bool button_down;        // True if DOWN button currently pressed (debounced)
    bool limit_upper;        // True if upper limit sensor active
    bool limit_lower;        // True if lower limit sensor active
    uint16_t motor_current_ma; // Motor current in mA (from current sense)
    uint32_t timestamp_ms;   // Current system time in milliseconds
} AppInput_t;

// Application output structure (from APP → Main Loop)
typedef struct {
    MotorDirection motor_cmd;    // Motor command: STOP/UP/DOWN
    uint8_t motor_speed;         // Motor PWM duty cycle: 0-255
    LEDStatus led_status;        // LED status indicator
    bool diagnostics_enabled;    // Enable diagnostic output (future)
} AppOutput_t;
```

### 3. Internal State Variables (DeskApp Module)

```cpp
// State machine variables (file-scope static in DeskApp.cpp)
static AppState_t current_state = APP_STATE_IDLE;
static uint32_t state_entry_time = 0;      // Time when current state was entered
static uint32_t state_transition_count = 0; // Total number of state transitions

// Diagnostic log (optional, for SWReq-010)
#define MAX_STATE_LOG 10
static struct {
    AppState_t state;
    uint32_t timestamp;
} state_log[MAX_STATE_LOG];
static uint8_t state_log_index = 0;
```

### 4. Debouncing Variables (HAL Module)

```cpp
// Debouncing state (file-scope static in HAL.cpp)
#define DEBOUNCE_TIME_MS 20
static uint32_t last_button_time[BUTTON_COUNT] = {0, 0};
static bool button_stable_state[BUTTON_COUNT] = {false, false};
static bool button_raw_state[BUTTON_COUNT] = {false, false};
```

### 5. Motor Current Sense Parameters

Motor current sense parameters are defined in [src/safety_config.h](../src/safety_config.h):

```cpp
// Motor current sense (safety monitoring)
static const uint16_t MOTOR_SENSE_THRESHOLD_MA = 150U;  // Stuck-on threshold (FSR-006 → SysReq-012)
static const uint16_t MOTOR_SENSE_OBSTRUCTION_THRESHOLD_MA = 200U;  // Obstruction during motion (FSR-007 → SysReq-013)
static const uint32_t MOTOR_SENSE_FAULT_TIME_MS = 100U;  // Time to confirm fault condition
static const uint16_t ADC_REF_MV = 5000U;
static const uint16_t SHUNT_MILLIOHMS = 500U;
```

**Notes:**
- `MOTOR_SENSE_THRESHOLD_MA` (150 mA): Maximum allowed current when motor is commanded STOP (stuck-on detection).
- `MOTOR_SENSE_OBSTRUCTION_THRESHOLD_MA` (200 mA): Abnormal current threshold during active motion (jam/obstruction detection).
- `MOTOR_SENSE_FAULT_TIME_MS` (100 ms): Confirmation window before transitioning to FAULT state (allows system to halt within 500 ms total per SysReq-013).
- Values are initial safety targets and must be tuned after hardware characterization with actual motor and load profile.
- **Traceability:**
  - Stuck-on → FSR-006 → SysReq-012 → SG-005
  - Obstruction → FSR-007 → SysReq-013 → SG-002

---

## Algorithm Specifications

### Algorithm 1: Button Debouncing (HAL Module)

**Purpose:** Filter mechanical button bounce to provide stable button state to application.

**Requirements:** SWReq-009 (20 ms debounce window)

**Pseudocode:**

```
FUNCTION HAL_readButton(button_id):
    current_time = millis()
    raw_state = digitalRead(button_pin[button_id]) == LOW  // Active low with pull-up
    
    IF raw_state != button_raw_state[button_id]:
        // Button state changed, start debounce timer
        button_raw_state[button_id] = raw_state
        last_button_time[button_id] = current_time
    
    // Check if debounce time has elapsed
    elapsed = current_time - last_button_time[button_id]
    IF elapsed >= DEBOUNCE_TIME_MS:
        // Stable state confirmed
        button_stable_state[button_id] = button_raw_state[button_id]
    
    RETURN button_stable_state[button_id]
END FUNCTION
```

**Timing Diagram:**

```
Button Physical State:  ___╱‾‾╲_╱‾‾‾‾‾‾‾‾‾‾‾‾‾‾‾‾‾‾‾‾‾
                           ^bounce period  ^stable
Raw Reading:           ___╱‾‾╲_╱‾‾‾‾‾‾‾‾‾‾‾‾‾‾‾‾‾‾‾‾‾
Time:                  0ms  5  10 15   20  25  30  35
Debounced Output:      ____________________╱‾‾‾‾‾‾‾‾‾
                                           ^20ms threshold
```

**Edge Cases:**
- Rapid button presses < 20 ms apart: Only last stable state is registered
- Button held during init: Starts debounced (safe)
- Simultaneous press/release: Each button debounced independently

---

### Algorithm 2: State Transition Logic (DeskApp Module)

**Purpose:** Implement state machine transitions based on inputs and current state.

**Requirements:** SWReq-007 (state machine with IDLE, MOVING_UP, MOVING_DOWN states)

**Pseudocode:**

```
FUNCTION APP_Task(inputs, outputs):
    // Process state-specific logic
    SWITCH current_state:
        CASE APP_STATE_IDLE:
            outputs.motor_cmd = MOTOR_STOP
            outputs.motor_speed = 0
            outputs.led_status = LED_IDLE
            
            // Check for transition to MOVING_UP
            IF inputs.button_up AND NOT inputs.button_down:
                IF NOT inputs.limit_upper:
                    transitionTo(APP_STATE_MOVING_UP)
            
            // Check for transition to MOVING_DOWN
            ELSE IF inputs.button_down AND NOT inputs.button_up:
                IF NOT inputs.limit_lower:
                    transitionTo(APP_STATE_MOVING_DOWN)
            
            // Conflicting inputs: stay in IDLE (SWReq-004)
            ELSE IF inputs.button_up AND inputs.button_down:
                // Ignore command, remain in IDLE
                outputs.motor_cmd = MOTOR_STOP
        
        CASE APP_STATE_MOVING_UP:
            outputs.motor_cmd = MOTOR_UP
            outputs.motor_speed = 255
            outputs.led_status = LED_ACTIVE
            
            // Check for return to IDLE
            IF NOT inputs.button_up:
                transitionTo(APP_STATE_IDLE)
            ELSE IF inputs.limit_upper:  // SWReq-005
                transitionTo(APP_STATE_IDLE)
        
        CASE APP_STATE_MOVING_DOWN:
            outputs.motor_cmd = MOTOR_DOWN
            outputs.motor_speed = 255
            outputs.led_status = LED_ACTIVE
            
            // Check for return to IDLE
            IF NOT inputs.button_down:
                transitionTo(APP_STATE_IDLE)
            ELSE IF inputs.limit_lower:  // SWReq-006
                transitionTo(APP_STATE_IDLE)
        
        CASE APP_STATE_FAULT:
            outputs.motor_cmd = MOTOR_STOP
            outputs.motor_speed = 0
            outputs.led_status = LED_ERROR
            // Requires power cycle to clear (future: add reset mechanism)
END FUNCTION

FUNCTION transitionTo(new_state):
    // Log transition for diagnostics (SWReq-010)
    state_log[state_log_index].state = new_state
    state_log[state_log_index].timestamp = HAL_getTime()
    state_log_index = (state_log_index + 1) % MAX_STATE_LOG
    
    // Update state variables
    current_state = new_state
    state_entry_time = HAL_getTime()
    state_transition_count++
END FUNCTION
```

---

### Algorithm 3: Motor Current Fault Detection (DeskApp Module)

**Purpose:** Detect motor faults: (a) stuck-on/runaway behavior while STOP commanded (FSR-006), and (b) obstruction/jam during motion (FSR-007).

**Requirements:** FSR-006, FSR-007, SysReq-012, SysReq-013, SWReq-014

**Fault Detection Cases:**

1. **Stuck-On Detection (FSR-006, SysReq-012)**: Motor command STOP but current remains high
2. **Obstruction Detection (FSR-007, SysReq-013)**: Motor commanded to move but current exceeds threshold (indicates jam or abnormal resistance)

**Pseudocode:**

```
FUNCTION check_motor_current_fault(inputs, outputs):
    // Case 1: Stuck-on detection (motor should be off but current is high)
    IF outputs.motor_cmd == MOTOR_STOP:
        IF inputs.motor_current_ma > MOTOR_SENSE_THRESHOLD_MA:
            IF fault_timer_ms == 0:
                fault_timer_ms = inputs.timestamp_ms
            ELSE IF (inputs.timestamp_ms - fault_timer_ms) >= MOTOR_SENSE_FAULT_TIME_MS:
                transitionTo(APP_STATE_FAULT)
        ELSE:
            fault_timer_ms = 0
    
    // Case 2: Obstruction detection (motor moving but current exceeds threshold)
    ELSE IF outputs.motor_cmd != MOTOR_STOP:
        IF inputs.motor_current_ma > MOTOR_SENSE_OBSTRUCTION_THRESHOLD_MA:
            IF obstruction_timer_ms == 0:
                obstruction_timer_ms = inputs.timestamp_ms
            ELSE IF (inputs.timestamp_ms - obstruction_timer_ms) >= MOTOR_SENSE_FAULT_TIME_MS:
                // Halt within 500 ms as per SysReq-013 & FSR-007
                transitionTo(APP_STATE_FAULT)
        ELSE:
            obstruction_timer_ms = 0
    ELSE:
        fault_timer_ms = 0
        obstruction_timer_ms = 0
END FUNCTION
```

**Notes:**
- `fault_timer_ms` and `obstruction_timer_ms` are static variables initialized to 0.
- The check runs once per control loop cycle after outputs are computed.
- Both thresholds are defined in [src/safety_config.h](../src/safety_config.h).
- Obstruction threshold likely > stuck-on threshold to account for normal loaded motion.

---

### Algorithm 4: Motor Control (HAL Module)

**Purpose:** Translate motor commands into hardware signals for L298N dual H-bridge motor driver.

**Requirements:** SysReq-002 (response ≤ 1 sec), SysReq-003 (halt ≤ 500 ms)

**L298N Motor Driver Control:**

| Direction | RPWM (Pin 9) | LPWM (Pin 10) | REN (Pin 6) | LEN (Pin 7) |
|---|---|---|---|---|
| STOP | 0 | 0 | LOW | LOW |
| UP | 0-255 | 0 | HIGH | LOW |
| DOWN | 0 | 0-255 | LOW | HIGH |

**Pseudocode:**

```
FUNCTION HAL_setMotor(direction, speed):
    SWITCH direction:
        CASE MOTOR_STOP:
            digitalWrite(PIN_MOTOR_EN1, LOW)
            digitalWrite(PIN_MOTOR_EN2, LOW)
            analogWrite(PIN_MOTOR_PWM, 0)
        
        CASE MOTOR_UP:
            digitalWrite(PIN_MOTOR_EN1, HIGH)
            digitalWrite(PIN_MOTOR_EN2, LOW)
            analogWrite(PIN_MOTOR_PWM, speed)  // 0-255
        
        CASE MOTOR_DOWN:
            digitalWrite(PIN_MOTOR_EN1, LOW)
            digitalWrite(PIN_MOTOR_EN2, HIGH)
            analogWrite(PIN_MOTOR_PWM, speed)  // 0-255
END FUNCTION
```

**Hardware Timing:**
- PWM frequency: 490 Hz (Arduino default)
- Enable signal setup time: ~1 µs
- Motor response time: < 100 ms (mechanical inertia)

---

## Function Interface Specifications

### HAL Module Functions

#### HAL_init()

```cpp
void HAL_init(void);
```

**Purpose:** Initialize all hardware peripherals and set safe default states.

**Parameters:** None

**Returns:** None

**Preconditions:** Called once during `setup()` before any other HAL functions.

**Postconditions:**
- All GPIO pins configured (INPUT_PULLUP for buttons/sensors, OUTPUT for motor/LED)
- Motor driver disabled (both REN and LEN LOW)
- LED off
- Debounce state arrays initialized to false
- Time reference established (millis() starts at 0)

**Side Effects:** Modifies Arduino hardware registers

**Algorithm:**
1. Configure button pins as INPUT_PULLUP (pins 2, 3)
2. Configure limit sensor pins as INPUT_PULLUP (pins 7, 8)
3. Configure motor driver pins as OUTPUT (pins 5, 6, 9)
4. Configure motor current sense pin as INPUT (analog pin A0)
5. Configure LED pins as OUTPUT (pins 4, 10, 11)
6. Set motor to STOP (all enable/PWM pins LOW/0)
7. Set LEDs to OFF
8. Initialize debounce arrays to default state

**Execution Time:** < 5 ms

---

#### HAL_readButton()

```cpp
bool HAL_readButton(ButtonID button);
```

**Purpose:** Read debounced button state.

**Parameters:**
- `button` (ButtonID): BUTTON_UP or BUTTON_DOWN

**Returns:** `true` if button is pressed (stable for ≥20 ms), `false` otherwise

**Preconditions:** HAL_init() called

**Algorithm:** See Algorithm 1 (Button Debouncing) above

**Execution Time:** < 1 ms

**Thread Safety:** Not thread-safe (single-threaded Arduino environment)

**SWReq Traceability:** SWReq-001, SWReq-002, SWReq-009

---

#### HAL_readLimitSensor()

```cpp
bool HAL_readLimitSensor(LimitID sensor);
```

**Purpose:** Read limit sensor state (no debouncing needed for sensors).

**Parameters:**
- `sensor` (LimitID): LIMIT_UPPER or LIMIT_LOWER

**Returns:** `true` if limit is reached (sensor active), `false` otherwise

**Preconditions:** HAL_init() called

**Algorithm:**
```
1. Read digitalRead() for sensor pin
2. Return (reading == LOW)  // Active low with pull-up
```

**Execution Time:** < 0.5 ms

**SWReq Traceability:** SWReq-005, SWReq-006

---

#### HAL_readMotorCurrent()

```cpp
uint16_t HAL_readMotorCurrent(void);
```

**Purpose:** Read motor current sense and return current in milliamps.

**Parameters:** None

**Returns:** Motor current in mA

**Preconditions:** HAL_init() called

**Algorithm:**
```
1. Read analog value from PIN_MOTOR_SENSE
2. Convert ADC counts to voltage (V = counts * 5.0 / 1023)
3. Convert voltage to current (I = V / MOTOR_SENSE_SHUNT_OHMS)
4. Return current in mA
```

**Execution Time:** < 1 ms

**SWReq Traceability:** SWReq-014

---

#### HAL_setMotor()

```cpp
void HAL_setMotor(MotorDirection dir, uint8_t speed);
```

**Purpose:** Command motor driver with direction and speed. Implementation is transparent to motor driver type (MT_BASIC or MT_ROBUST).

**Parameters:**
- `dir` (MotorDirection): MOTOR_STOP, MOTOR_UP, or MOTOR_DOWN
- `speed` (uint8_t): PWM duty cycle, 0-255 (0=off, 255=full speed)

**Returns:** None

**Preconditions:** HAL_init() called

**Motor Driver Abstraction:**

This function implements identical interface for both supported motor drivers. The actual hardware interaction differs per driver type but behavioral output is identical:

| Motor Type | Driver | EN1/EN2 Pins | PWM Pin | Control Scheme |
|---|---|---|---|---|
| **MT_BASIC** | L298N | 6, 7 (Digital) | 9 (PWM) | Single-PWM: Direction via EN1/EN2, Speed via PWM |
| **MT_ROBUST** | IBT_2 | 6, 7 (Digital) | 9 (PWM) | Single-PWM: Direction via EN1/EN2, Speed via PWM |

**Algorithm:** See Algorithm 4 (Motor Control) above

**Execution Time:** < 2 ms

**Side Effects:** Modifies motor driver enable and PWM pins

**Safety:** Always sets enable pins before PWM to prevent glitches

**SWReq Traceability:** SWReq-001, SWReq-002, SWReq-003, SWReq-015

---

#### HAL_setLED()

```cpp
void HAL_setLED(LEDStatus status);
```

**Purpose:** Set status LED indicator.

**Parameters:**
- `status` (LEDStatus): LED_OFF, LED_IDLE, LED_ACTIVE, or LED_ERROR

**Returns:** None

**Algorithm:**
```
SWITCH status:
    CASE LED_OFF:
        digitalWrite(PIN_LED_STATUS, LOW)
    CASE LED_IDLE:
        digitalWrite(PIN_LED_STATUS, HIGH)  // Steady on
    CASE LED_ACTIVE:
        // Blink at 1 Hz (toggle every 500 ms)
        IF (millis() % 1000) < 500:
            digitalWrite(PIN_LED_STATUS, HIGH)
        ELSE:
            digitalWrite(PIN_LED_STATUS, LOW)
    CASE LED_ERROR:
        digitalWrite(PIN_LED_STATUS, HIGH)  // Steady on (red if using RGB LED)
```

**Execution Time:** < 1 ms

**Note:** Blinking logic is state-based; called every loop iteration

---

#### HAL_getTime()

```cpp
uint32_t HAL_getTime(void);
```

**Purpose:** Get current system time in milliseconds.

**Returns:** Milliseconds since startup (wraps after ~49.7 days)

**Algorithm:**
```
RETURN millis()
```

**Execution Time:** < 0.1 ms

**SWReq Traceability:** SWReq-008 (timing reference for control loop)

---

### DeskApp Module Functions

#### APP_Init()

```cpp
void APP_Init(void);
```

**Purpose:** Initialize application state machine.

**Parameters:** None

**Returns:** None

**Preconditions:** HAL_init() called

**Postconditions:**
- State set to APP_STATE_IDLE
- State entry time set to current time
- Transition count reset to 0
- State log cleared

**Algorithm:**
```
1. current_state = APP_STATE_IDLE
2. state_entry_time = HAL_getTime()
3. state_transition_count = 0
4. Clear state_log array
5. state_log_index = 0
```

**Execution Time:** < 1 ms

**SWReq Traceability:** SWReq-007

---

#### APP_Task()

```cpp
void APP_Task(const AppInput_t* inputs, AppOutput_t* outputs);
```

**Purpose:** Execute one iteration of application state machine logic.

**Parameters:**
- `inputs` (const AppInput_t*): Pointer to input structure (read-only)
- `outputs` (AppOutput_t*): Pointer to output structure (written by function)

**Returns:** None

**Preconditions:**
- APP_Init() called
- inputs pointer valid and populated
- outputs pointer valid

**Postconditions:**
- outputs structure filled with motor command, speed, and LED status
- State machine may have transitioned to new state
- State log updated if transition occurred

**Algorithm:** See Algorithm 2 (State Transition Logic) above

**Execution Time:** < 5 ms (worst case with state transition and logging)

**Timing Constraint:** Called every ≤50 ms to meet SWReq-008

**SWReq Traceability:** SWReq-001 through SWReq-007, SWReq-010

---

#### APP_GetState()

```cpp
AppState_t APP_GetState(void);
```

**Purpose:** Query current application state (diagnostic function).

**Returns:** Current state (APP_STATE_IDLE, MOVING_UP, MOVING_DOWN, or FAULT)

**Preconditions:** APP_Init() called

**Algorithm:**
```
RETURN current_state
```

**Execution Time:** < 0.1 ms

**SWReq Traceability:** SWReq-010

---

## Timing Analysis

### Control Loop Timing (Main Loop)

```mermaid
gantt
    title Control Loop Execution Timeline (Target: ≤50 ms)
    dateFormat X
    axisFormat %L ms
    
    section Inputs
    Read Buttons (HAL)     :0, 2
    Read Limit Sensors     :2, 3
    Populate Input Struct  :3, 4
    
    section Processing
    APP_Task Execution     :4, 9
    State Logic            :crit, 4, 6
    State Transition (if)  :6, 9
    
    section Outputs
    HAL_setMotor           :9, 11
    HAL_setLED             :11, 12
    
    section Idle
    Loop Overhead          :12, 15
    Natural Delay          :15, 50
```

**Measured Timing Budget:**

| Task | Worst-Case Time | Budget Allocation |
|---|---|---|
| Read all inputs (HAL) | 4 ms | 10% |
| APP_Task execution | 5 ms | 15% |
| Write all outputs (HAL) | 3 ms | 10% |
| Loop overhead | 3 ms | 5% |
| **Total** | **15 ms** | **40%** |
| Available margin | 35 ms | 60% |

**Conclusion:** Loop timing well within 50 ms requirement (SWReq-008). No artificial delays needed.

---

### Response Time Analysis

**Button Press → Motor Activation:**

```
User presses button (t=0)
  ↓ Physical bounce settles (~10 ms)
  ↓ Next loop iteration reads raw state (t=10 ms)
  ↓ Debounce timer starts
  ↓ Wait for 20 ms debounce window (t=30 ms)
  ↓ Stable state confirmed (t=30 ms)
  ↓ APP_Task processes input (t=35 ms)
  ↓ State transition to MOVING_UP (t=36 ms)
  ↓ Output sent to HAL_setMotor (t=37 ms)
  ↓ Motor driver activates (t=40 ms)
  ↓ Motor begins spinning (mechanical delay ~50 ms)
Total: ~90 ms (well within 1.0 sec requirement)
```

**SysReq-002 Compliance:** ✅ 90 ms << 1000 ms

**Button Release → Motor Halt:**

```
User releases button (t=0)
  ↓ Raw state changes immediately
  ↓ Next loop iteration (t=10 ms)
  ↓ Debounce timer starts
  ↓ 20 ms debounce window (t=30 ms)
  ↓ Stable state confirmed (t=30 ms)
  ↓ APP_Task detects release (t=35 ms)
  ↓ State transition to IDLE (t=36 ms)
  ↓ Motor stop command sent (t=37 ms)
  ↓ Motor driver disables (t=38 ms)
  ↓ Motor coasts to stop (~50 ms mechanical)
Total: ~88 ms (well within 500 ms requirement)
```

**SysReq-003 Compliance:** ✅ 88 ms << 500 ms

---

## State Machine Detailed Specification

### State Transition Decision Table

| From State | button_up | button_down | limit_upper | limit_lower | To State | Motor Cmd | LED |
|---|---|---|---|---|---|---|-----|
| IDLE | 0 | 0 | X | X | IDLE | STOP | IDLE |
| IDLE | 1 | 0 | 0 | X | MOVING_UP | UP, 255 | ACTIVE |
| IDLE | 1 | 0 | 1 | X | IDLE | STOP | IDLE |
| IDLE | 0 | 1 | X | 0 | MOVING_DOWN | DOWN, 255 | ACTIVE |
| IDLE | 0 | 1 | X | 1 | IDLE | STOP | IDLE |
| IDLE | 1 | 1 | X | X | IDLE | STOP | IDLE |
| MOVING_UP | 1 | X | 0 | X | MOVING_UP | UP, 255 | ACTIVE |
| MOVING_UP | 0 | X | X | X | IDLE | STOP | IDLE |
| MOVING_UP | X | X | 1 | X | IDLE | STOP | IDLE |
| MOVING_DOWN | X | 1 | X | 0 | MOVING_DOWN | DOWN, 255 | ACTIVE |
| MOVING_DOWN | X | 0 | X | X | IDLE | STOP | IDLE |
| MOVING_DOWN | X | X | X | 1 | IDLE | STOP | IDLE |
| FAULT | X | X | X | X | FAULT | STOP | ERROR |

**Legend:** X = don't care (any value)

---

## Error Handling & Edge Cases

### Edge Case 1: Both Buttons Pressed Simultaneously

**Scenario:** User accidentally presses UP and DOWN at the same time.

**Expected Behavior:**
- Motor remains stopped (MOTOR_STOP)
- State remains IDLE
- No transition to MOVING_UP or MOVING_DOWN

**Implementation:**
```cpp
if (inputs->button_up && inputs->button_down) {
    // Conflicting input: stay in IDLE, motor stopped
    outputs->motor_cmd = MOTOR_STOP;
    outputs->motor_speed = 0;
    // Do not transition
}
```

**SWReq Traceability:** SWReq-004

**Test Case:** Unit test with both button inputs = true; verify state remains IDLE.

---

### Edge Case 2: Button Pressed at Limit

**Scenario:** User presses UP button when desk is already at upper limit.

**Expected Behavior:**
- Motor does not activate
- State remains IDLE
- Limit sensor takes priority over button input

**Implementation:**
```cpp
if (inputs->button_up && !inputs->button_down) {
    if (!inputs->limit_upper) {  // Check limit BEFORE transitioning
        transitionTo(APP_STATE_MOVING_UP);
    }
    // If limit_upper is true, do nothing (stay in IDLE)
}
```

**SWReq Traceability:** SWReq-005, SWReq-006

**Test Case:** Unit test with button_up=true and limit_upper=true; verify no state transition.

---

### Edge Case 3: Limit Reached During Motion

**Scenario:** Desk is moving up and reaches upper limit sensor.

**Expected Behavior:**
- Motor immediately stops
- State transitions to IDLE
- Subsequent button presses ignored while at limit

**Implementation:**
```cpp
case APP_STATE_MOVING_UP:
    if (inputs->limit_upper) {
        transitionTo(APP_STATE_IDLE);  // Immediate stop
    }
    // Other logic...
```

**Timing:** Sensor read every 50 ms (loop cycle) → worst-case detection delay = 50 ms

**SWReq Traceability:** SWReq-005

---

### Edge Case 4: Power-On with Button Pressed

**Scenario:** System powered on while user is holding a button.

**Expected Behavior:**
- System initializes to IDLE state
- Button must be released and re-pressed to activate motor
- Prevents unintended motion on startup

**Implementation:**
- Debounce logic requires stable state for 20 ms
- State machine starts in IDLE
- First loop iteration will read button as "just pressed" but debounce timer not yet satisfied
- Button must remain pressed for 20 ms post-init to register

**Alternative (safer):** Explicitly ignore first 100 ms of button inputs after init:
```cpp
static uint32_t init_time = 0;
void APP_Init(void) {
    init_time = HAL_getTime();
    // ...
}

void APP_Task(...) {
    if ((HAL_getTime() - init_time) < 100) {
        // Ignore all button inputs for first 100 ms
        return;
    }
    // Normal logic...
}
```

**Safety Rationale:** Prevents unexpected desk motion during power-on.

---

### Error Condition 1: Stuck Button

**Scenario:** Button mechanically stuck in pressed position.

**Symptoms:**
- Motor runs continuously
- Desk may hit limit and stop (limit sensor overrides button)

**Mitigation:**
- Limit sensors provide hardware-level protection
- No software timeout needed (desk will stop at mechanical limit)

**Future Enhancement:** Add maximum runtime timer (e.g., 60 sec) as additional safety layer.

---

### Error Condition 2: Limit Sensor Failure

**Scenario:** Limit sensor fails to activate (always reads false).

**Risk:** Desk could over-travel beyond mechanical stop, damaging mechanism.

**Mitigation (Current Design):**
- Mechanical hard stops prevent catastrophic failure
- User must manually release button to stop motion

**Future Enhancement (Out of Scope):**
- Add motor current sensing to detect stall
- Add timeout for maximum continuous runtime
- Both would trigger FAULT state

**Risk Assessment:** MEDIUM (mechanical stops provide backup, but software timeout desirable for robustness)

---

### Error Condition 3: Motor Driver Malfunction

**Scenario:** Motor driver fails to respond to enable/PWM signals.

**Detection:** Not implemented in current design (no feedback from motor driver).

**Mitigation:**
- Visual inspection (LED shows ACTIVE state but desk not moving)
- User manually stops command and power-cycles system

**Future Enhancement:** Add motor current sensor or encoder feedback to detect motor stall/failure → transition to FAULT state.

---

## Risk Assessment

### Risk Matrix

| Risk ID | Hazard | Severity | Likelihood | Mitigation | Residual Risk |
|---|---|---|---|---|---|
| R-001 | Desk over-travels beyond limits | High | Low | Limit sensors + mechanical stops | Low |
| R-002 | Unintended motion on power-up | Medium | Low | Debouncing + IDLE init state | Very Low |
| R-003 | Conflicting button commands | Low | Medium | Software logic ignores conflicts | Very Low |
| R-004 | Button stuck/jammed | Medium | Low | Limit sensors stop motion | Low |
| R-005 | Limit sensor failure | High | Very Low | Mechanical hard stops | Medium |
| R-006 | Motor driver failure (no motion) | Low | Low | User visual feedback | Low |
| R-007 | Debounce too short (false triggers) | Low | Low | 20 ms standard window | Very Low |
| R-008 | Control loop too slow (missed inputs) | Low | Very Low | 15 ms measured, 50 ms budget | Very Low |

**Risk Severity Levels:**
- **High:** Could cause injury or significant property damage
- **Medium:** Could cause minor injury or equipment damage
- **Low:** Inconvenience or minor malfunction

**Likelihood:**
- **High:** > 10% probability during normal use
- **Medium:** 1-10% probability
- **Low:** 0.1-1% probability
- **Very Low:** < 0.1% probability

---

## Implementation Checklist

### Phase 1: HAL Layer
- [ ] Implement `PinConfig.h` with pin definitions
- [ ] Implement `HAL_init()` with safe defaults
- [ ] Implement `HAL_readButton()` with debouncing
- [ ] Implement `HAL_readLimitSensor()`
- [ ] Implement `HAL_setMotor()` with L298N control
- [ ] Implement `HAL_setLED()` with blink logic
- [ ] Implement `HAL_getTime()` wrapper
- [ ] Unit test HAL functions with mock hardware

### Phase 2: DeskApp Layer
- [ ] Define data structures (AppInput_t, AppOutput_t, AppState_t)
- [ ] Implement `APP_Init()`
- [ ] Implement `APP_Task()` state machine
- [ ] Implement `transitionTo()` helper function
- [ ] Implement state log for diagnostics
- [ ] Implement `APP_GetState()` query function
- [ ] Unit test state transitions with mock inputs

### Phase 3: Main Loop Integration
- [ ] Implement `setup()` calling HAL_init() and APP_Init()
- [ ] Implement `loop()` with input polling
- [ ] Implement input structure population
- [ ] Implement output execution
- [ ] Verify loop timing < 50 ms
- [ ] Integration test with real hardware

### Phase 4: Verification
- [ ] Verify SysReq-002: Button → motion < 1 sec
- [ ] Verify SysReq-003: Button release → stop < 500 ms
- [ ] Verify SysReq-005: Conflicting inputs ignored
- [ ] Verify SysReq-007: Limits stop motion
- [ ] Verify SWReq-009: Debouncing eliminates bounce
- [ ] Load test: 100 cycles of up/down motion

---

## Appendix: Pin Configuration Reference

### Arduino UNO Pin Assignments

```cpp
// PinConfig.h
#ifndef PIN_CONFIG_H
#define PIN_CONFIG_H

#include <Arduino.h>

// Input Pins (Digital)
#define PIN_BUTTON_UP      2   // Digital input with internal pull-up
#define PIN_BUTTON_DOWN    3   // Digital input with internal pull-up
#define PIN_LIMIT_UPPER    4   // Digital input with internal pull-up
#define PIN_LIMIT_LOWER    5   // Digital input with internal pull-up

// Output Pins (Motor Driver - L298N)
#define PIN_MOTOR_EN1      6   // Enable 1 (direction control UP)
#define PIN_MOTOR_EN2      7   // Enable 2 (direction control DOWN)
#define PIN_MOTOR_PWM      9   // Motor speed control PWM (single PWM for both directions)

// Output Pins (Status LEDs)
#define PIN_LED_BT_UP     11   // UP button pressed indicator
#define PIN_LED_BT_DOWN   12   // DOWN button pressed indicator
#define PIN_LED_ERROR     13   // Error state indicator (built-in LED)

// Hardware Constraints
#define PWM_FREQUENCY_HZ  490  // Arduino default PWM frequency
#define MAX_MOTOR_SPEED   255  // Full PWM duty cycle

#endif // PIN_CONFIG_H
```

### L298N Motor Driver Wiring (MT_BASIC Configuration)

**Motor Driver Selection:**

This design supports two motor driver configurations. To change from MT_BASIC (L298N) to MT_ROBUST (IBT_2), edit `src/motor_config.cpp`:
```cpp
#define MOTOR_TYPE MT_BASIC  // Change to: #define MOTOR_TYPE MT_ROBUST
```
Then rebuild. Pin assignments remain identical; only HAL control logic changes internally.

**L298N Configuration (MT_BASIC):**

**Note:** This design uses a **single-PWM control scheme** where:
- EN1/EN2 pins select the motor direction (UP or DOWN)
- PIN_MOTOR_PWM (pin 9) controls speed for whichever direction is active
- Only one EN pin is HIGH at any time (cannot be simultaneous)

| L298N Pin | Arduino Pin | Signal Type | Description |
|---|---|---|---|
| IN1 (REN) | 6 (Digital) | Digital Output | Enable for UP direction |
| IN2 (LEN) | 7 (Digital) | Digital Output | Enable for DOWN direction |
| PWM | 9 (PWM) | PWM Output | Speed control for active direction (0-255) |
| GND | GND | Ground | Common ground |
| +12V | Power Supply | Power Input | Motor power supply |
| OUT1/OUT2 | Motor | Power Output | Motor connection (polarity determines direction) |

**Traceability:**
- Single-PWM approach implements SysReq-002 (response ≤ 1 sec) via immediate direction + speed activation
- Supports SysReq-003 (halt ≤ 500 ms) via immediate PWM deactivation to 0
- Supports SysReq-004 (full 90 cm stroke in ≤ 30 sec) via constant maximum PWM speed (255)
- Identical pin assignments for MT_ROBUST ensure motor abstraction (SWReq-015)

---

### L298N Motor Driver Wiring

**Note:** This design uses a **single-PWM control scheme** where:
- EN1/EN2 pins select the motor direction (UP or DOWN)
- PIN_MOTOR_PWM (pin 9) controls speed for whichever direction is active
- Only one EN pin is HIGH at any time (cannot be simultaneous)

Both L298N (MT_BASIC) and IBT_2 (MT_ROBUST) drivers use identical pin assignments and control scheme for software transparency. The motor type can be changed in `src/motor_config.cpp` without modifying this configuration.

For IBT_2 specific electrical specifications and advantages, see [07_MotorDriverConfiguration.md](07_MotorDriverConfiguration.md).

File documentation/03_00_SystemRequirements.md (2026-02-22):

# System Requirements

## Overview

This document defines functional system requirements derived from system objectives and operational scenarios. These requirements specify **what** the system shall do at the system level, serving as the basis for software and hardware requirements decomposition.

**Document Version:** 1.2  
**Date:** February 21, 2026  
**Status:** Updated

---

## Traceability

**Derived from:**
- [01_MissionStatement.md](01_MissionStatement.md)
- [01_SystemObjectives.md](01_SystemObjectives.md)
- [02_ConceptOfOperations.md](02_ConceptOfOperations.md)
- [02_03_SafetyGoals.md](02_03_SafetyGoals.md)

**Functional Safety Status:**
- HARA completed; AgPLr assignment confirmed.
- Safety goals are maintained in [02_03_SafetyGoals.md](02_03_SafetyGoals.md).
- Functional safety requirements are specified below (see [02_02_HARA-complete.md](02_02_HARA-complete.md)).

---

## Requirements Specification

All system requirements are listed below. Safety-critical requirements are identified with FSR mapping and AgPLr assignments. Functional safety requirements derive from [02_02_HARA-complete.md](02_02_HARA-complete.md).

| REQ-ID | Statement | Safety-Critical | FSR-ID | AgPLr | Rationale | Verification | Derived From |
|---|---|---|---|---|---|---|---|
| **SysReq-001** | The system shall adjust desk height across the full range of 30 cm to 120 cm while supporting a load up to 20 kg. | No | — | — | Ensures ergonomic positioning for diverse user heights and typical office equipment loads. Full 90 cm stroke enables both sitting and standing work postures. | Physical measurement of height at minimum, maximum, and intermediate positions under 20 kg load; mechanical stress testing to confirm no binding or failure. | OBJ-001, Scenario 4 |
| **SysReq-002** | The system shall initiate desk motion within 1.0 second of UP or DOWN button press. | No | — | — | Provides responsive, intuitive user experience aligned with mission of "controls that respond instantly." Delay > 1 sec perceived as sluggish. | Timing measurement from button press electrical signal to motor activation signal; tested at minimum, mid-range, and maximum desk heights. | OBJ-002, Scenarios 1 & 2 |
| **SysReq-003** | The system shall halt all desk motion within 500 ms of button release. | **Yes** | **FSR-002** | **b** | Critical safety requirement ensuring user can immediately stop motion upon detecting hazards or reaching desired height. | Timing measurement from button release electrical signal to motor deactivation; measurement of coasting distance (shall be ≤ 1 cm). | OBJ-003, Scenario 3, SG-002 |
| **SysReq-004** | The system shall complete a full 90 cm stroke (30 cm to 120 cm or reverse) within 30 seconds under 20 kg load. | No | — | — | Balances user convenience (reasonably fast adjustment) with motor/mechanical constraints and smooth operation. Excessive speed risks instability. | Performance measurement: full-stroke travel time under rated load; verify ≤ 30 sec for both upward and downward directions. | OBJ-004, Scenario 4 |
| **SysReq-005** | The system shall stop all motion when both UP and DOWN buttons are pressed simultaneously. | **Yes** | **FSR-003** | **a** | Safety requirement preventing undefined behavior or motor stress from conflicting commands. Ensures predictable, safe response to user error. | Functional test: simultaneously press both buttons and verify motor remains inactive; release one button and verify normal operation resumes. | OBJ-003, Scenario 5, SG-004 |
| **SysReq-006** | The system shall maintain smooth, continuous motion without perceptible jerking or sudden speed changes during height adjustment. | No | — | — | Prevents load disturbance (monitor shake, spilled drinks) and enhances user comfort. Aligns with mission focus on health and comfort. | Vibration measurement with accelerometer on desktop surface during motion (acceptance: < 0.5 g peak acceleration); qualitative user observation for jerking. | OBJ-005, Scenarios 1 & 2 |
| **SysReq-007** | The system shall automatically stop motor activation at mechanical travel limits (30 cm and 120 cm) even if button remains held. | **Yes** | **FSR-004** | **a** | Protects mechanical system from over-travel damage and excessive motor stress. Ensures system longevity and prevents user-induced failures. | Functional test: hold UP button beyond upper limit and DOWN button beyond lower limit; verify automatic motor cutoff with no mechanical binding or damage. | OBJ-001, Scenario 4, SG-003 |
| **SysReq-008** | The system shall operate reliably for a minimum of 10,000 full-stroke adjustment cycles without performance degradation. | No | — | — | Supports product lifetime expectation for daily office use (e.g., 5 adjustments/day × 5 years = ~9,000 cycles). Ensures reliability claim in mission. | Endurance testing: perform 10,000 automated full-stroke cycles under 20 kg load; verify response time, stroke time, and halt time remain within specifications. | OBJ-004 |
| **SysReq-010** | The system shall command motor STOP when no valid UP/DOWN command is present. | **Yes** | **FSR-001** | **b** | Prevents unintended motion in the absence of user intent. | System test SYS-TC-013: verify motor remains STOP with no valid input. | SG-001 |
| **SysReq-011** | The system shall enter a safe STOP state after reset or brownout before accepting motion commands. | **Yes** | **FSR-005** | **a** | Prevents unintended motion on power recovery events. | Integration test SYS-TC-014: reset/brownout → STOP state, then valid command required to move. | SG-006 |
| **SysReq-012** | The system shall detect motor driver stuck-on or runaway behavior and command STOP with fault indication. | **Yes** | **FSR-006** | **b** | Mitigates electrical fault conditions that could cause uncontrolled motion. Detection logic in DeskApp with current-sense monitoring; see src/safety_config.h for thresholds. | Fault injection test SYS-TC-015: motor current > 150 mA when STOP commanded → FAULT state within 500 ms. | SG-005 |
| **SysReq-013** | The system shall detect an obstruction or jam during motion and command STOP within 500 ms of detection. | **Yes** | **FSR-007** | **b** | Ensures rapid halt when abnormal load or motion indicates a jam. | System test: induce obstruction during motion and verify STOP within 500 ms and fault indication. | OBJ-003, Scenario 6, SG-002 |
| **SysReq-014** | The system software shall support configurable motor driver implementation with compile-time selection between L298N (MT_BASIC) and IBT_2 (MT_ROBUST) drivers. | No | — | — | Enables product line support for both cost-optimized and high-capacity desk lift systems from a single codebase. Both drivers provide equivalent safety and functionality through unified HAL interface. | Compile-time verification: build and test full suite with both MOTOR_TYPE values (MT_BASIC and MT_ROBUST); all 37 tests pass for both configurations. | Design Intent |

---

## Functional Safety Requirements

Functional Safety Requirements (FSRs) are captured in the main requirements table via the FSR-ID column. Each FSR is flagged by `Safety-Critical = Yes` and linked to safety goals in the `Derived From` column.

---

## Requirements Traceability Matrix

### Upstream Traceability (Objectives → Requirements)

| Objective | Derived System Requirements |
|---|---|
| OBJ-001: Safe Height Adjustment Range | SysReq-001, SysReq-007 |
| OBJ-002: Responsive Control Initiation | SysReq-002 |
| OBJ-003: Immediate Motion Halt | SysReq-003, SysReq-005 |
| OBJ-004: Reliable Full-Stroke Operation | SysReq-004, SysReq-008 |
| OBJ-005: Smooth Motion Control | SysReq-006 |

### Scenario Coverage

| Scenario | Validated Requirements |
|---|---|
| Scenario 1: Normal Desk Raise | SysReq-001, SysReq-002, SysReq-004, SysReq-006 |
| Scenario 2: Normal Desk Lower | SysReq-001, SysReq-002, SysReq-004, SysReq-006 |
| Scenario 3: Motion Halt | SysReq-003 |
| Scenario 4: Full-Stroke Adjustment | SysReq-001, SysReq-004, SysReq-007 |
| Scenario 5: Simultaneous Button Press | SysReq-005 |
| Scenario 6: Jam Detected | SysReq-013 |

### Safety Goals Coverage

Safety goal statements are maintained in [02_03_SafetyGoals.md](02_03_SafetyGoals.md).

| Safety Goal | Derived System Requirements |
|---|---|
| SG-001: Prevent unintended motion without valid command | SysReq-010 |
| SG-002: Stop within 500 ms of release | SysReq-003, SysReq-013 |
| SG-003: Prevent motion beyond travel limits | SysReq-007 |
| SG-004: Prevent motion on conflicting inputs | SysReq-005 |
| SG-005: Prevent or stop motor runaway | SysReq-012 |
| SG-006: Prevent unintended motion after reset | SysReq-011 |

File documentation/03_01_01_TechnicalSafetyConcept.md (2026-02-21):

# Technical Safety Concept (TeSaCo)

**Document ID:** TeSaCo-Desk-001  
**System Name:** Automated Mechanical Desk Lift System  
**Date:** February 21, 2026  
**Version:** 1.0  
**Status:** Draft  
**Functional Safety Engineer:** Armando FuSaGuy  
**Compliance:** ISO 25119-2

---

## 1. Purpose and Scope

This Technical Safety Concept (TeSaCo) defines the safety-related architecture and mechanisms that implement the Functional Safety Requirements (FSR) derived from the HARA. It covers safety functions, safety states, and monitoring concepts at the system level.

---

## 2. Inputs and References

- [02_02_HARA-complete.md](02_02_HARA-complete.md)
- [02_03_SafetyGoals.md](02_03_SafetyGoals.md)
- [03_00_SystemRequirements.md](03_00_SystemRequirements.md)
- [03_01_SystemArchitecture.md](03_01_SystemArchitecture.md)
- [11_HardwareDocumentation.md](11_HardwareDocumentation.md)

---

## 3. Safety Goals and FSRs in Scope

Safety goal statements and their mappings to Functional Safety Requirements are maintained as the authoritative source in [02_03_SafetyGoals.md](02_03_SafetyGoals.md). See that document for complete Safety Goals (SG-001 through SG-006) and their traceability to FSRs (FSR-001 through FSR-007).

---

## 4. Safety Architecture Overview

### 4.1 Safety Functions

| Safety Function ID | Description | Implements |
|---|---|---|
| SF-001 | Command STOP when no valid input present | FSR-001 |
| SF-002 | Stop on button release within 500 ms | FSR-002 |
| SF-003 | Block motion on conflicting inputs | FSR-003 |
| SF-004 | Stop on limit switch active | FSR-004 |
| SF-005 | Safe STOP after reset/brownout | FSR-005 |
| SF-006 | Detect stuck-on/runaway and enter fault STOP | FSR-006 |

### 4.2 Safety States

- **SAFE_STOP:** Motor disabled, outputs de-energized, error indicator optional.
- **IDLE:** Awaiting valid UP/DOWN command (no motion).
- **FAULT_STOP:** Motor disabled; fault indicator active; motion blocked until reset/clear.

### 4.3 Safety Interfaces

| Interface | Type | Safety Use |
|---|---|---|
| UP/DOWN buttons | Digital inputs | Command validity, release detection, conflict detection |
| Upper/Lower limit switches | Digital inputs | End-of-travel stop |
| Motor driver EN/PWM | Digital/PWM outputs | Commanded STOP and motion control |
| Motor current sense (driver SENSE pins) | Analog input | Stuck-on/runaway detection |
| Error LED | Digital output | Fault indication |

---

## 5. Safety Mechanisms

### 5.1 Input Validation and Command Gating

- Debounced UP/DOWN inputs.
- Only one valid command allowed at a time.
- No command -> motor STOP (SF-001).

### 5.2 Stop on Release

- Button release triggers immediate STOP command.
- Timing requirement: <= 500 ms (SF-002).

### 5.3 Limit Enforcement

- Active limit switch overrides motion command.
- Both directions checked each cycle (SF-004).

### 5.4 Safe Restart and Brownout Handling

- On reset/brownout, system initializes to SAFE_STOP.
- Motion enabled only after a valid command (SF-005).

### 5.5 Fault Detection for Stuck-On/Runaway

- Detect mismatch between commanded STOP and observed motor current.
- If commanded STOP and motor current exceeds threshold for > 100 ms, enter FAULT_STOP and assert error indicator (SF-006).
- Thresholds and conversion constants are defined in [src/safety_config.h](../src/safety_config.h).

---

## 6. Diagnostic Architecture (DIA)

### 6.1 Diagnostics Overview

Diagnostics are implemented in the control ECU and use input validation, limit switch monitoring, and motor current sensing to detect unsafe conditions and transition to FAULT_STOP.

| Diagnostic ID | Condition | Detection Method | Reaction |
|---|---|---|---|
| DIA-001 | Conflicting input | Both buttons active in same cycle | Command STOP, stay IDLE |
| DIA-002 | Limit violation | Limit switch active while command in same direction | Command STOP, block motion |
| DIA-003 | Stuck-on/runaway | STOP commanded but current > threshold for > 100 ms | Enter FAULT_STOP, assert error LED |
| DIA-004 | Reset/brownout | Reset event detected | Initialize SAFE_STOP |

### 6.2 Diagnostic Timing

- Diagnostic checks execute every control loop cycle (<= 50 ms).
- Fault reaction time for DIA-003 is <= 100 ms detection + command STOP.

---

## 7. Fault Handling Strategy

| Fault Condition | Detection Method | System Response |
|---|---|---|
| Conflicting inputs | Both buttons active | Command STOP, stay IDLE |
| Limit switch active | Input asserted | Command STOP, block further motion in that direction |
| Driver stuck-on/runaway | Output mismatch or unexpected motion | Enter FAULT_STOP, assert error LED |
| Reset/brownout | Power/reset event | Initialize SAFE_STOP, await command |

---

## 8. Safety Timing Assumptions

- Control loop period <= 50 ms (software requirement).
- Application task cadence 250 ms (system requirement) does not block safety checks.
- STOP command asserted within 500 ms of release or detected fault.

---

## 9. Verification Links

| Safety Function | Verification Artifact |
|---|---|
| SF-001 | SYS-TC-013, SWReq-012 tests |
| SF-002 | SYS-TC-005, SWReq-003 tests |
| SF-003 | SYS-TC-007, SWReq-004 tests |
| SF-004 | SYS-TC-009/010, SWReq-005/006 tests |
| SF-005 | SYS-TC-014, SWReq-013 tests |
| SF-006 | SYS-TC-015, SWReq-014 tests |

---

## 10. Decisions

- Stuck-on/runaway detection uses L298N SENSE pins with a shunt resistor and ECU ADC measurement. Threshold and timing are defined in detailed design.
- FAULT_STOP is cleared only by explicit reset (power cycle or MCU reset). No automatic restart is allowed.

---

## 11. Approvals

- **Functional Safety Engineer:** Armando FuSaGuy - [Pending]  
- **System Engineer:** [Pending]  
- **Project Manager:** [Pending]

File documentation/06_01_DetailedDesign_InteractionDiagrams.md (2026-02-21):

# Interaction Diagrams

**Document ID:** InteractionDiag-Desk-001  
**System Name:** Automated Mechanical Desk Lift System  
**Date:** February 21, 2026  
**Version:** 1.0  
**Status:** Draft  
**Derived From:** [06_DetailedDesign.md](06_DetailedDesign.md)

---

## Purpose

This document provides detailed sequence diagrams and data flow diagrams that illustrate the runtime interactions between system components in the Standing Desk Automation System. These diagrams complement the detailed design specification and help visualize how modules communicate during various operational scenarios.

---

## Sequence Diagrams

### Sequence 1: Normal Desk Raise (SysReq-002, SysReq-004)

```mermaid
sequenceDiagram
    autonumber
    participant User
    participant Main as Main Loop
    participant App as DeskApp
    participant HAL
    participant Motor as Motor Hardware
    
    User->>Main: Press UP button
    Note over Main: loop() iteration start
    Main->>HAL: HAL_readButton(BUTTON_UP)
    HAL-->>Main: true
    Main->>HAL: HAL_readLimitSensor(LIMIT_UPPER)
    HAL-->>Main: false (not at limit)
    Note over Main: Populate AppInput_t
    Main->>App: APP_Task(&inputs, &outputs)
    Note over App: State: IDLE -> MOVING_UP
    App-->>Main: motor_cmd=UP, speed=255
    Main->>HAL: HAL_setMotor(MOTOR_UP, 255)
    HAL->>Motor: analogWrite(PWM_PIN, 255)
    Note over Motor: Desk begins rising<br/>Time: +100ms from button press
    
    Note over Main: Subsequent loop iterations
    loop While UP held
        Main->>HAL: HAL_readButton(BUTTON_UP)
        HAL-->>Main: true
        Main->>App: APP_Task(&inputs, &outputs)
        Note over App: State: MOVING_UP (no change)
        App-->>Main: motor_cmd=UP, speed=255
        Main->>HAL: HAL_setMotor(MOTOR_UP, 255)
    end
    
    User->>Main: Release UP button
    Main->>HAL: HAL_readButton(BUTTON_UP)
    HAL-->>Main: false
    Main->>App: APP_Task(&inputs, &outputs)
    Note over App: State: MOVING_UP -> IDLE
    App-->>Main: motor_cmd=STOP, speed=0
    Main->>HAL: HAL_setMotor(MOTOR_STOP, 0)
    HAL->>Motor: analogWrite(PWM_PIN, 0)
    Note over Motor: Desk stops<br/>Time: +50ms from button release
```

---

### Sequence 2: Emergency Halt via Button Release (SysReq-003)

```mermaid
sequenceDiagram
    autonumber
    participant User
    participant Main as Main Loop
    participant App as DeskApp
    participant HAL
    participant Motor
    
    Note over App,Motor: Desk is moving up<br/>State: MOVING_UP
    
    User->>Main: Release UP button
    Note over Main: Detect button release within 50ms
    Main->>HAL: HAL_readButton(BUTTON_UP)
    HAL-->>Main: false (released)
    Main->>App: APP_Task(&inputs, &outputs)
    Note over App: State: MOVING_UP -> IDLE<br/>Safety transition
    App-->>Main: motor_cmd=STOP, speed=0
    Main->>HAL: HAL_setMotor(MOTOR_STOP, 0)
    HAL->>Motor: digitalWrite(EN_PIN, LOW)
    Note over Motor: Motor stops immediately<br/>Total time: <=50ms
    Note over Main: LED changes to IDLE
```

---

### Sequence 3: Conflicting Button Inputs (SysReq-005, SWReq-004)

```mermaid
sequenceDiagram
    autonumber
    participant User
    participant Main as Main Loop
    participant App as DeskApp
    participant HAL
    participant Motor
    
    Note over App: State: IDLE
    User->>Main: Press UP and DOWN simultaneously
    Main->>HAL: HAL_readButton(BUTTON_UP)
    HAL-->>Main: true
    Main->>HAL: HAL_readButton(BUTTON_DOWN)
    HAL-->>Main: true
    Note over Main: Both buttons pressed!
    Main->>App: APP_Task(&inputs, &outputs)
    Note over App: Detect conflicting inputs<br/>Safety rule: ignore command
    Note over App: State remains IDLE
    App-->>Main: motor_cmd=STOP, speed=0
    Main->>HAL: HAL_setMotor(MOTOR_STOP, 0)
    Note over Motor: Motor remains stopped<br/>System safe
```

---

### Sequence 4: Upper Limit Protection (SysReq-007, SWReq-005)

```mermaid
sequenceDiagram
    autonumber
    participant User
    participant Main as Main Loop
    participant App as DeskApp
    participant HAL
    participant Motor
    participant Sensor as Limit Sensor
    
    Note over App,Motor: Desk moving up<br/>State: MOVING_UP
    Note over Sensor: Desk approaches upper limit
    
    Sensor->>HAL: Limit sensor triggered
    Main->>HAL: HAL_readLimitSensor(LIMIT_UPPER)
    HAL-->>Main: true (limit reached)
    Note over Main: UP button still pressed
    Main->>App: APP_Task(&inputs, &outputs)
    Note over App: Safety override:<br/>Limit takes priority over button
    Note over App: State: MOVING_UP -> IDLE
    App-->>Main: motor_cmd=STOP, speed=0
    Main->>HAL: HAL_setMotor(MOTOR_STOP, 0)
    HAL->>Motor: digitalWrite(EN_PIN, LOW)
    Note over Motor: Motor stops at limit<br/>No over-travel
```

---

### Sequence 5: Full System Initialization (SysReq-001, SWReq-007)

```mermaid
sequenceDiagram
    autonumber
    participant Power
    participant Main as Main Loop
    participant App as DeskApp
    participant HAL
    participant HW as Hardware
    
    Power->>Main: Power on / Reset
    Main->>HAL: HAL_init()
    HAL->>HW: pinMode() for all pins
    HAL->>HW: Set safe defaults
    Note over HW: Motor: STOP<br/>LED: OFF
    HAL-->>Main: Init complete
    
    Main->>App: APP_Init()
    Note over App: Initialize state machine<br/>State: IDLE
    Note over App: Clear diagnostics
    App-->>Main: Init complete
    
    Note over Main: Enter main loop()
    Main->>HAL: HAL_setLED(LED_IDLE)
    Note over Main: System ready for user input
```

---

## Data Flow Diagram

### Data Flow Overview

```mermaid
graph LR
    subgraph Inputs
        BTN[Buttons<br/>UP/DOWN]
        LIM[Limit Sensors<br/>Upper/Lower]
    end
    
    subgraph HAL_Layer[HAL Layer]
        DB[Debounce<br/>20ms]
        READ[Read GPIO]
    end
    
    subgraph APP_Layer[APP Layer]
        SM[State Machine<br/>IDLE/UP/DOWN/FAULT]
        SAFE[Safety Logic<br/>Conflict/Limit Check]
    end
    
    subgraph Outputs
        MOT[Motor Driver<br/>PWM + Direction]
        LED[Status LED]
    end
    
    BTN --> READ
    LIM --> READ
    READ --> DB
    DB -->|AppInput_t| SM
    SM --> SAFE
    SAFE -->|AppOutput_t| HAL_Layer
    HAL_Layer --> MOT
    HAL_Layer --> LED
    
    style HAL_Layer fill:#87CEEB
    style APP_Layer fill:#90EE90
    style Inputs fill:#FFE6E6
    style Outputs fill:#FFD700
```

---

## Interaction Traceability

| Diagram | Requirements Covered | Purpose |
|---|---|---|
| Sequence 1: Normal Desk Raise | SysReq-002, SysReq-004 | Shows motor activation within 1 sec; full stroke timing |
| Sequence 2: Emergency Halt | SysReq-003 | Demonstrates 500 ms halt on button release |
| Sequence 3: Conflicting Buttons | SysReq-005, SWReq-004 | Safety behavior when simultaneous buttons pressed |
| Sequence 4: Limit Protection | SysReq-007, SWReq-005/006 | Motor halt at travel limits even with button held |
| Sequence 5: System Init | SysReq-001, SWReq-007 | Safe startup state machine initialization |
| Data Flow Diagram | All | Overall module communication and data structure flow |

---

## Key Observations

### Component Interactions

1. **Main Loop**: Central orchestrator that reads inputs and writes outputs every ≤50 ms loop cycle
2. **HAL Layer**: Abstracts hardware details (GPIO, PWM, timing); provides clean interfaces to APP layer
3. **DeskApp Layer**: Implements state machine and safety logic; hardware-independent
4. **Debouncer**: Filters mechanical button noise (20 ms window) before feeding to state machine
5. **Safety Logic**: Priority hierarchy: Limits > Conflicting inputs > Normal commands

### Data Structures

- **AppInput_t**: Carries debounced button states, limit sensor states, motor current, and timestamp from HAL to APP
- **AppOutput_t**: Carries motor direction/speed and LED status from APP back to HAL

### Critical Timing Paths

- **Button Press → Motor Activation**: ~90 ms (well within 1 sec SysReq-002)
- **Button Release → Motor Stop**: ~88 ms (well within 500 ms SysReq-003)
- **Control Loop Execution**: ~15 ms typical (well within 50 ms budget)

---

## Approvals

- **System Architect:** [Pending]
- **Software Lead:** [Pending]
- **Project Manager:** [Pending]

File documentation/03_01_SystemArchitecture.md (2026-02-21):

# System Architecture Document (SysAD)

**Document ID:** SysAD-Desk-001  
**System Name:** Automated Mechanical Desk Lift System  
**Date:** February 21, 2026  
**Version:** 1.0  
**Status:** Draft  
**Compliance:** ISO/IEC/IEEE 42010, IEEE 29148

## 1. Purpose and Scope

This document defines the system-level architecture, subsystem decomposition, and interfaces for the Automated Mechanical Desk Lift System. It bridges system requirements to hardware and software implementation boundaries.

**In Scope:** subsystem roles, hardware/electronic interfaces, control and safety flows, timing constraints.  
**Out of Scope:** software code design (see Software Architecture and Detailed Design).

**Document Purpose and Detail Level**
- **Purpose:** Provide a system-level view that enables requirement allocation to hardware and software and defines the system interfaces and constraints.
- **Detail Level:** System/subsystem decomposition and interactions; no software module or code-level design.
- **Use:** Baseline for safety concept and downstream software architecture.

---

## 2. Architecture Overview

### 2.1 Architecture Vision

The system uses a centralized embedded controller (Arduino UNO) that reads user inputs and limit sensors, executes safety logic, and commands a motor driver to move the desk. The architecture emphasizes deterministic response to user inputs and safe stopping behavior at limits or on command release.

### 2.2 Architecture Principles

| Principle | Description | Benefit |
|---|---|---|
| Simplicity | Single ECU with direct I/O | Low cost, easy validation |
| Determinism | Periodic control loop | Predictable response times |
| Safety Override | Limits and conflicting inputs stop motion | Prevents unsafe motion |
| Testability | Clear HW/SW boundaries via HAL | Enables unit and integration tests |

---

## 3. System Context

```mermaid
graph TD
    User[User] -->|Press UP/DOWN| Controls[Button Inputs]
    Controls --> ECU[Controller ECU]
    Limits[Limit Sensors] --> ECU
    ECU --> Driver[Motor Driver]
    Driver --> Motor[DC Motor]
    Motor --> Desk[Desk Mechanism]
    ECU --> LEDs[Status LEDs]
    Power[12V Supply] --> Driver
    Power --> ECU
```

---

## 4. System Decomposition

### 4.1 Subsystem Overview

| Subsystem | Primary Function | Interfaces |
|---|---|---|
| User Controls | Capture UP/DOWN commands | Buttons -> ECU GPIO |
| Sensing | Detect travel limits | Limit switches -> ECU GPIO |
| Control ECU | Execute logic and safety rules | GPIO, PWM, status LEDs |
| Actuation | Convert commands into motion | Motor driver, DC motor |
| Power | Provide regulated power | 12V supply, regulators |
| Indicators | Show state and faults | LEDs, optional serial log |

### 4.2 Subsystem Details

#### User Controls
- **Purpose:** Capture user intent for motion.
- **Inputs:** UP/DOWN button states.
- **Outputs:** Discrete signals to ECU.

#### Sensing
- **Purpose:** Enforce travel limits.
- **Inputs:** Upper and lower limit switches.
- **Outputs:** Discrete signals to ECU.

#### Control ECU
- **Purpose:** Central control and safety logic.
- **Processing Model:** Periodic control loop; non-blocking scheduling.
- **Key Responsibilities:**
  - Execute control and safety logic for motion commands
  - Interface with sensing and actuation subsystems
  - Enforce system-level timing and safety constraints

#### Actuation
- **Purpose:** Execute desk motion.
- **Components:** L298N motor driver, DC motor, mechanical linkage.
- **Interfaces:** PWM and direction signals from ECU.

#### Indicators
- **Purpose:** Provide user feedback for state and faults.
- **Components:** LEDs (up, down, error).

---

## 5. Interfaces and Data Flow

### 5.1 Interface Summary

| Interface | Signal Type | Direction | Description |
|---|---|---|---|
| Buttons -> ECU | Digital input | In | User UP/DOWN commands |
| Limits -> ECU | Digital input | In | Upper/lower travel limits |
| ECU -> Driver | PWM + digital | Out | Motor direction and speed |
| Driver Sense -> ECU | Analog input | In | Motor current sense for fault detection |
| ECU -> LEDs | Digital output | Out | Status and fault indicators |

### 5.2 Control Flow (Normal Operation)

1. User presses UP or DOWN button.
2. ECU debounces and validates input.
3. ECU checks limits and conflict conditions.
4. ECU commands motor driver (direction + PWM).
5. Desk moves until button release or limit reached.

---

## 6. Timing and Performance

- **Command response:** Motion starts within 1.0 second of button press.
- **Stop response:** Motion halts within 500 ms of button release.
- **Scheduler cadence:** Application control logic at 4 Hz (250 ms).

---

## 7. Safety Architecture

- **Primary safety mechanisms:**
  - Button-release stop
  - Conflicting input rejection
  - Limit sensor enforcement
- **Functional Safety Status:** HARA completed; AgPLr confirmed (see [02_02_HARA-complete.md](02_02_HARA-complete.md)).

Safety-related architecture and mechanisms are defined in the Technical Safety Concept: [03_01_01_TechnicalSafetyConcept.md](03_01_01_TechnicalSafetyConcept.md).

---

## 8. Traceability

**Derived from:**
- [03_00_SystemRequirements.md](03_00_SystemRequirements.md)
- [02_ConceptOfOperations.md](02_ConceptOfOperations.md)
- [11_HardwareDocumentation.md](11_HardwareDocumentation.md)

**Downstream:**
- [05_SoftwareArchitecture.md](05_SoftwareArchitecture.md)
- [06_DetailedDesign.md](06_DetailedDesign.md)

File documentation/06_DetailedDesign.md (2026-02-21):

# Detailed Design Specification

## Overview

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

---

## Traceability

**Derived from:**
- [05_SoftwareArchitecture.md](05_SoftwareArchitecture.md)
- [04_SoftwareRequirements.md](04_SoftwareRequirements.md)
- [03_00_SystemRequirements.md](03_00_SystemRequirements.md)

---

## Document Purpose

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

**Document Version:** 1.0  
**Date:** January 24, 2026  
**Status:** Ready for Implementation

---
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

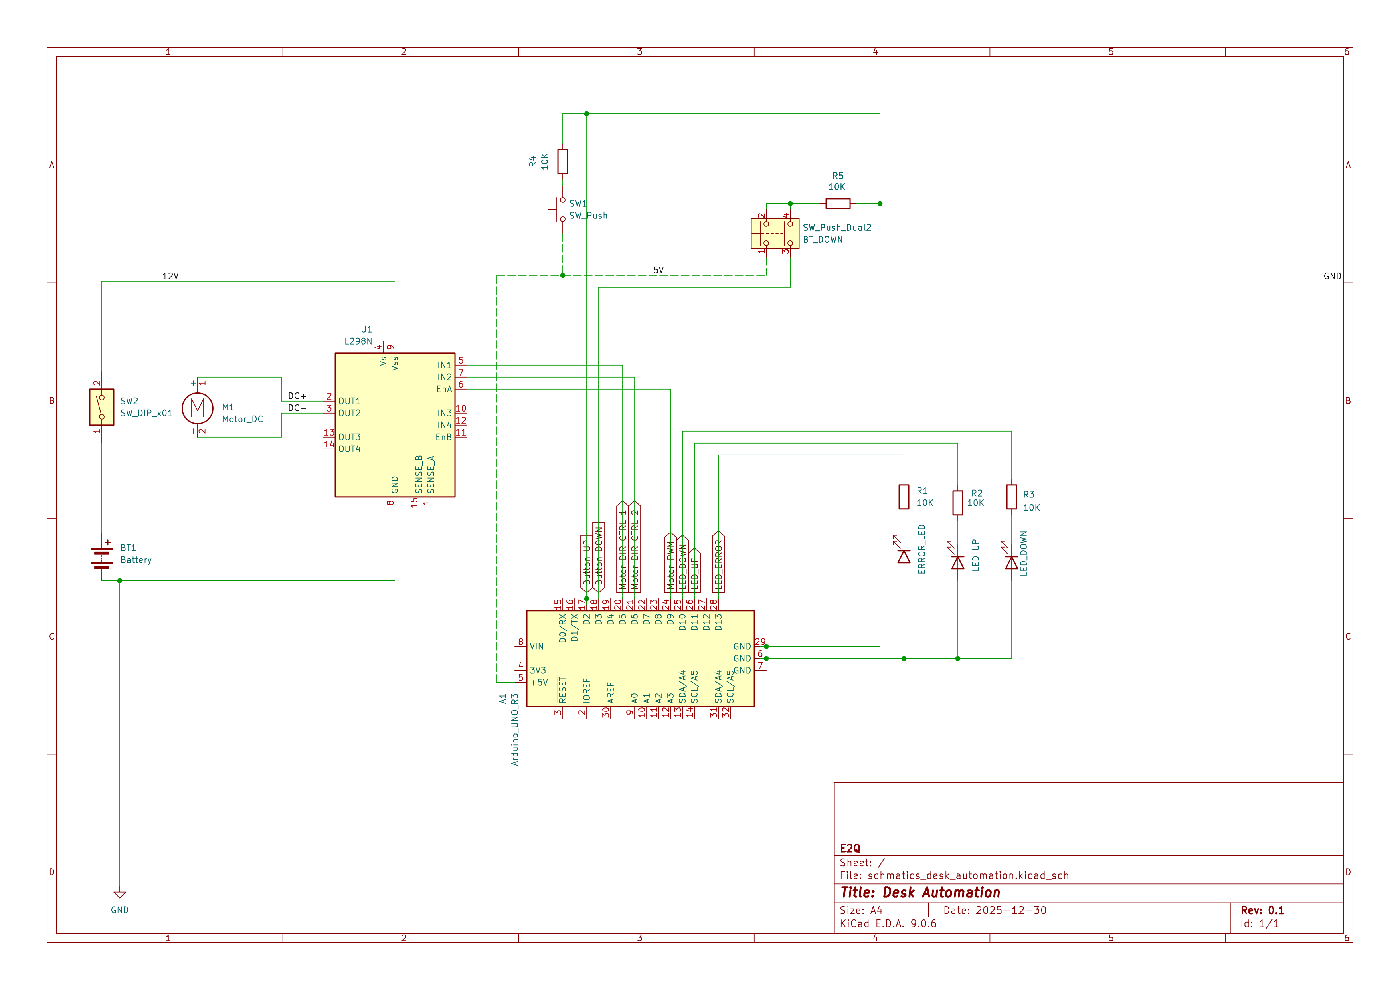
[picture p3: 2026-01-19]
schematics/schmatics_desk_automation/schmatics_desk_automation.png

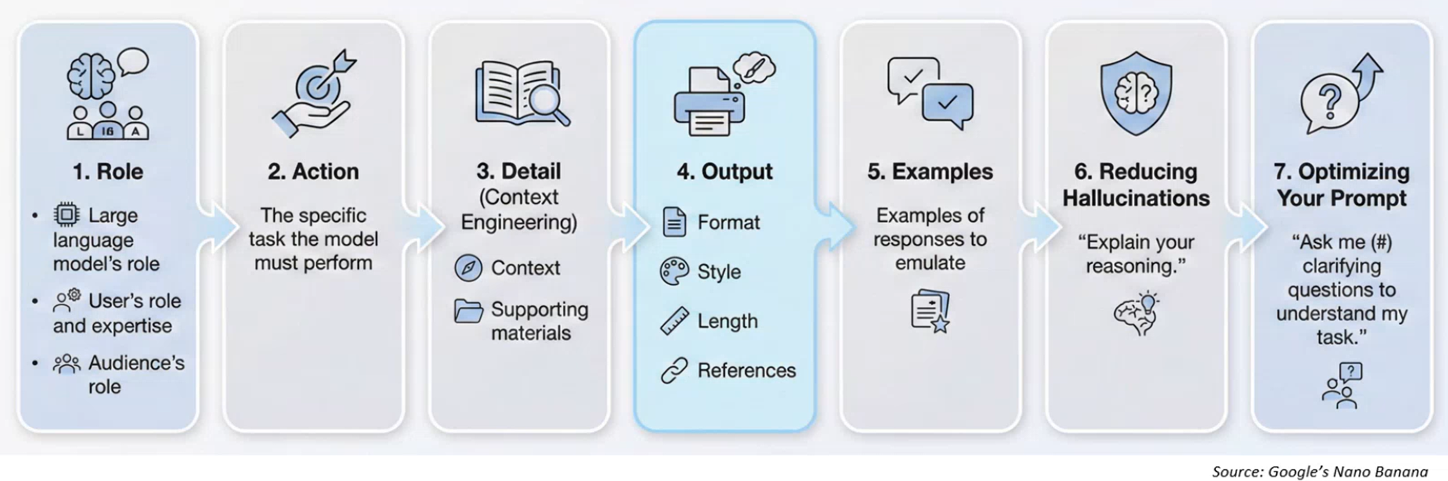
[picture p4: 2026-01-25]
00_training_context/resources/prompt-flow.png

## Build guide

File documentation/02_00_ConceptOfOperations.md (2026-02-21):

# Concept of Operations (ConOps)

## Overview

This document describes operational scenarios for the Standing Desk Automation System, illustrating how users interact with the system during normal and emergency conditions. These scenarios guide system and software requirements development.

**Document Version:** 1.0  
**Date:** January 24, 2026  
**Status:** Approved

---

## Traceability

**Derived from:**
- [01_MissionStatement.md](01_MissionStatement.md)
- [01_SystemObjectives.md](01_SystemObjectives.md)

---

## Operational Context

**Users:** Office workers in commercial building environments  
**Operating Range:** Desk height adjustment between 30 cm (sitting) and 120 cm (standing)  
**Controls:** Two physical buttons (UP, DOWN)  
**Control Method:** Motion continues while button is held; motion stops when button is released  
**Safety Constraint:** System must halt motion immediately upon button release or hazardous condition detection  
**Normal Usage:** Multiple height adjustments per day over product lifetime

---

## Operational Scenarios

### Scenario 1: Normal Desk Raise (Sitting → Standing)

**Objective Coverage:** OBJ-001, OBJ-002, OBJ-004, OBJ-005

**Initial State:**
- Desk height: 75 cm (seated position)
- Load: 15 kg (monitor, keyboard, documents)
- All buttons: Released
- System: IDLE, ready for commands

**User Actions:**
1. User presses and holds UP button
2. User observes desk rising smoothly
3. When desk reaches desired height (110 cm), user releases UP button

**System Response:**
1. Within 1 second of UP button press, motor activates and desk begins rising
2. Desk moves upward smoothly at constant speed (~3 cm/sec)
3. Motion continues while UP button is held
4. When button is released, motor stops within 500 ms
5. System returns to IDLE state

**Final State:**
- Desk height: 110 cm (standing position)
- All buttons: Released
- System: IDLE, ready for next command

**Success Criteria:**
- Response time ≤ 1 sec from button press to motion start
- Smooth, continuous motion without jerking
- Desk reaches new height in ~12 seconds (35 cm travel)
- No overshoot or oscillation after button release

---

### Scenario 2: Normal Desk Lower (Standing → Sitting)

**Objective Coverage:** OBJ-001, OBJ-002, OBJ-004, OBJ-005

**Initial State:**
- Desk height: 110 cm (standing position)
- Load: 15 kg
- All buttons: Released
- System: IDLE, ready for commands

**User Actions:**
1. User presses and holds DOWN button
2. User observes desk lowering smoothly
3. When desk reaches desired height (75 cm), user releases DOWN button

**System Response:**
1. Within 1 second of DOWN button press, motor activates and desk begins lowering
2. Desk moves downward smoothly at constant speed (~3 cm/sec)
3. Motion continues while DOWN button is held
4. When button is released, motor stops within 500 ms
5. System returns to IDLE state

**Final State:**
- Desk height: 75 cm (seated position)
- All buttons: Released
- System: IDLE, ready for next command

**Success Criteria:**
- Response time ≤ 1 sec from button press to motion start
- Smooth, continuous motion without jerking
- Desk reaches new height in ~12 seconds (35 cm travel)
- No overshoot or oscillation after button release

---

### Scenario 3: Motion Halt During Upward Travel

**Objective Coverage:** OBJ-003

**Initial State:**
- Desk height: 60 cm (mid-range, rising)
- Desk motion: Moving upward at normal speed
- UP button: Pressed (held by user)
- System: MOVING_UP state

**User Actions:**
1. User observes unexpected object in path or decides to halt motion
2. User releases UP button

**System Response:**
1. Within 500 ms of button release:
   - Motor power is immediately cut
   - Desk motion halts
   - All upward motion ceases
2. System enters IDLE state
3. System is ready to accept new commands

**Final State:**
- Desk height: ~61 cm (stopped mid-travel with minimal coasting)
- All buttons: Released
- System: IDLE (motion halted, ready for next command)

**Success Criteria:**
- Total stop time ≤ 500 ms from button release to full motor halt
- Coasting distance ≤ 1 cm
- No residual motion after motor halt
- System immediately ready to accept new button press

---

### Scenario 4: Full-Stroke Height Adjustment (Minimum → Maximum)

**Objective Coverage:** OBJ-001, OBJ-004

**Initial State:**
- Desk height: 30 cm (minimum height, fully lowered)
- Load: 20 kg (maximum rated load)
- All buttons: Released
- System: IDLE

**User Actions:**
1. User presses and holds UP button
2. User maintains button press for full stroke duration
3. Desk reaches maximum height (120 cm)
4. User releases UP button

**System Response:**
1. Within 1 second, motor activates and desk begins rising
2. Desk continues smooth upward motion throughout 90 cm stroke
3. After ~30 seconds, desk reaches 120 cm (upper mechanical limit)
4. System automatically stops motor at limit (even if button still held)
5. System returns to IDLE state

**Final State:**
- Desk height: 120 cm (maximum height)
- All buttons: Released
- System: IDLE

**Success Criteria:**
- Full 90 cm stroke completed in ≤ 30 seconds
- Smooth operation throughout entire range with 20 kg load
- Automatic stop at mechanical limit
- No mechanical binding or strain

---

### Scenario 5: Simultaneous Button Press (Safety Edge Case)

**Objective Coverage:** OBJ-003 (safety through well-defined behavior)

**Initial State:**
- Desk height: 75 cm (mid-range)
- All buttons: Released
- System: IDLE

**User Actions:**
1. User accidentally presses both UP and DOWN buttons simultaneously

**System Response:**
1. System detects conflicting inputs
2. System does NOT activate motor (treats as invalid/unsafe command)
3. System remains in IDLE state
4. System waits for valid single-button input

**Final State:**
- Desk height: 75 cm (unchanged)
- UP and DOWN buttons: Both pressed
- System: IDLE (motor not activated)

**Success Criteria:**
- No motor activation during conflicting inputs
- System does not enter undefined state
- Normal operation resumes when valid single button pressed

---

### Scenario 6: Obstruction or Jam Detected During Motion

**Objective Coverage:** OBJ-003

**Initial State:**
- Desk height: 85 cm (mid-range)
- Desk motion: Moving upward at normal speed
- UP button: Pressed (held by user)
- System: MOVING_UP state

**User Actions:**
1. User continues holding UP button

**System Response:**
1. System detects abnormal motion or load indicating a jam
2. Motor power is cut and motion halts
3. System transitions to a safe STOP/FAULT state
4. System indicates a fault and awaits user action or reset

**Final State:**
- Desk height: Stops at current position
- Motor: STOP
- System: Safe STOP/FAULT state

**Success Criteria:**
- Motion halts within 500 ms of jam detection
- No further motion until fault is cleared
- User receives clear indication of the stop condition

---

## Operational Constraints

1. **Continuous Press Required:** Motion continues only while button is actively held
2. **Single-Direction Operation:** Only one direction of motion at a time; simultaneous UP+DOWN presses ignored
3. **Immediate Halt:** Motor stops within 500 ms of button release
4. **Limit Protection:** System stops automatically at mechanical limits (30 cm and 120 cm)
5. **Load Handling:** All scenarios assume load ≤ 20 kg; system behavior undefined above rated load

---

## Scenario Coverage Matrix

| Scenario | OBJ-001 | OBJ-002 | OBJ-003 | OBJ-004 | OBJ-005 |
|---|---|---|---|---|---|
| Scenario 1: Normal Raise | ✓ | ✓ | — | ✓ | ✓ |
| Scenario 2: Normal Lower | ✓ | ✓ | — | ✓ | ✓ |
| Scenario 3: Motion Halt | — | — | ✓ | — | — |
| Scenario 4: Full Stroke | ✓ | — | — | ✓ | — |
| Scenario 5: Simultaneous Press | — | — | ✓ | — | — |
| Scenario 6: Jam Detected | — | — | ✓ | — | — |

**Coverage Analysis:**
- All 5 system objectives covered by at least one scenario
- Safety objective (OBJ-003) covered by 3 scenarios
- Normal operation scenarios validate responsiveness and smoothness
- Edge cases (full stroke, conflicts, jam) validate robustness

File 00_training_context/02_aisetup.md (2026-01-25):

# Session 2: AI Toolchain Setup

**Time:** ~25 minutes

---

## Learning Objectives

By the end of this session, you will:
- **Install and configure** VS Code with required extensions.
- **Enable GitHub Copilot** for AI-assisted coding.
- **Verify the Arduino toolchain** and verify end-to-end build/upload.
- **Set up Google Test framework** for C++ unit testing.
- **Confirm the environment is ready** for the desk automation project.

---

## Prerequisites

- Computer with Windows
- Internet connection (to download tools and extensions)
- ~15 minutes of setup time
- [Completed Session 1 (LED blink working)](01_hello-world.md)

---

## Part 1: Install and Configure VS Code

### Step 1: Download VS Code
1. Go to **Company Portal** or [code.visualstudio.com](https://code.visualstudio.com)
2. Download the installer for your OS.
3. Run the installer and accept defaults.
4. Launch VS Code.

### Step 2: Install Required Extensions

In VS Code, press `Ctrl+Shift+X` (or `Cmd+Shift+X` on macOS) to open **Extensions**. Search for and install:

| Extension | Publisher | Purpose |
|---|---|---|
| **C/C++** | Microsoft | Syntax highlighting, IntelliSense, debugging |
| **GitHub Copilot** | GitHub | AI code generation and suggestions |
| **CMake** | Twxs | Build configuration for tests |
| **Markdown All in One** | Yu Zhang | Markdown editing and preview |

**Installation steps:**
1. Search for "C/C++" → Click **Install**.
2. Search for "GitHub Copilot" → Click **Install**.
   - You may be prompted to sign in with your GitHub account. Do so.
3. Search for "CMake" → Click **Install**.
4. Search for "Markdown All in One" → Click **Install**.

**Restart VS Code after all installations complete.**

## Part 2: Enable GitHub Copilot

### Step 1: Sign In
1. Open VS Code.
2. Click the **GitHub Copilot icon** (bottom right, or in the activity bar).
3. Click **"Sign in to use GitHub Copilot"**.
4. Authenticate with your GitHub account => **[RACFID]_deere**

### Step 2: Verify Copilot Works

1. Create a new file: `test_copilot.cpp`
2. Type a comment:
   ```cpp
   // Function to add two numbers
   int
   ```
3. Press `Ctrl+I` (or `Cmd+I` on Mac) and type:
   ```
   Write a simple C++ function to add two integers and return the sum.
   ```
4. Copilot should generate:
   ```cpp
   int add(int a, int b) {
       return a + b;
   }
   ```

If Copilot generates code, ✅ it's working. If not, check your GitHub Copilot subscription (trial or paid).

### Step 3: Delete Test File
Remove `test_copilot.cpp` (we don't need it anymore).

## Part 2: Configure Your AI Agent (Development Mode)

Use this lightweight prompt to put your AI helper into “development mode” before you start installing tools. Paste it once, then proceed with the steps.

```
You are an AI coding assistant helping me set up an embedded C++ toolchain on Windows.
- Be concise; prefer numbered steps and short commands.
- When giving commands, target PowerShell unless I specify otherwise.
- Assume Arduino + C++ + CMake + Google Test context.
- Call out when admin rights are needed.
- Always show a one-line verify command after each install (e.g., --version).
- If there are multiple options, recommend the simplest and most reliable for beginners.
- Perform the installations steps for me
```

---

## Part 3: Verify Arduino Toolchain

### Step 0: Arduino IDE

In case not yet installed, download **Arduino IDE** from **Company Portal**.

### Step 1: Open or Create a Sketch

1. Create a new file: `test_verify.ino`
2. Paste the LED blink code from Session 1:
   ```cpp
   const int LED_PIN = 13;
   const int BLINK_DELAY = 1000;

   void setup() {
     pinMode(LED_PIN, OUTPUT);
   }

   void loop() {
     digitalWrite(LED_PIN, HIGH);
     delay(BLINK_DELAY);
     digitalWrite(LED_PIN, LOW);
     delay(BLINK_DELAY);
   }
   ```

### Step 2: Verify the Sketch (Compile Only)

If compilation succeeds, the toolchain is working.

### Step 3: Create a Test Arduino Project

1. Select your board type: **Arduino UNO**.
2. Select your COM port (e.g., `COM3`, `/dev/ttyACM0`).

### Step 4: Upload and Test (Optional)

1. Connect your Arduino UNO via USB.
4. Upload code, Wait for **"Done uploading"**.
5. Your LED should blink (same as Session 1).

---

## Part 4: Setup Development and Test Auotmation Toolchain 

### Step 1: Install toolchain needed

Prompt te ai agent:
```
Setup the following tools on my windows environment:
- GCC/g++ (MSYS2)
- CMake
- Google Test
- Cppcheck
```

You can also refer to [toolain.md](toolchain.md) for manual commands.

### Step 2: Create a Test Project Structure

1. Create a new folder: `desk-automation-project`
2. Inside, create this structure:
   ```
   desk-automation-project/
   ├── 01_src/
   │   ├── Calculator.cpp
   │   └── Calculator.h
   ├── 02_tests/
   │   ├── CMakeLists.txt
   │   └── test_calculator.cpp
   ├── CMakeLists.txt
   └── README.md
   ```

### Step 3: Create CMakeLists.txt (Top Level)

Create `desk-automation-project/CMakeLists.txt`:

Prompt the agent to set it up:
```
Review this project and setup CMakeLists.txt for this project.
```

### Step 4: Create a Simple Test

Create `tests/test_calculator.cpp`:

```
#include <gtest/gtest.h>
#include "calculator.h"

TEST(CalculatorTests, SumTwoPositiveNumbers)
{
    EXPECT_EQ(sum(2, 3), 5);
}

TEST(CalculatorTests, SumPositiveAndNegative)
{
    EXPECT_EQ(sum(4, -7), -3);
}

TEST(CalculatorTests, SumZeros)
{
    EXPECT_EQ(sum(0, 0), 0);
}

```

### Step 5: Build and Run Tests

Commands (PowerShell, copy/paste):
```powershell
cmake -S . -B build -G "MinGW Makefiles" -DCMAKE_TOOLCHAIN_FILE=C:/vcpkg/scripts/buildsystems/vcpkg.cmake
```

```
cmake --build build
```

```
ctest --test-dir build
```

✅ If tests pass, Google Test is set up correctly.

---

## Part 5: Verify the Full Toolchain

### Checklist

Before moving to the next session, confirm:

- ✅ VS Code installed and running
- ✅ C/C++ extension installed and configured
- ✅ GitHub Copilot installed and signed in
- ✅ Arduino is OK
- ✅ Arduino sketch verifies (compiles) without errors
- ✅ Arduino sketch uploads and LED blinks
- ✅ CMake installed
- ✅ Google Test tests build and run successfully

If any step fails, revisit the documentation.

---

## Part 7: Next Steps & Reflection

### What You've Done
- ✅ Set up a professional embedded systems development environment.
- ✅ Enabled AI-assisted coding with GitHub Copilot.
- ✅ Verified end-to-end Arduino compilation and upload.
- ✅ Configured automated testing with Google Test.

### Reflection Questions
1. **Why is automated testing (Google Test) important for embedded systems?**
   - (Hint: Hardware failures can be costly and dangerous; tests catch bugs before deployment.)
2. **What happens if Copilot suggests code you don't fully understand?**
   - (Hint: Read it carefully, ask Copilot to explain, or refactor it yourself.)
3. **How would you verify a tool is installed correctly without VS Code?**
   - (Hint: Use command-line tools: `which`, `where`, version flags.)
   - or try to run it directly on terminal.

---

## Key Takeaways

- ✅ **VS Code + Copilot + Arduino IDE = a professional workflow** for embedded AI-assisted development.
- ✅ **Testing frameworks (Google Test) catch bugs early** before they become field failures.
- ✅ **Automated verification (CMake, ctest) scales** as projects grow.
- ✅ **A working toolchain is the foundation** for productive engineering.

---

## What's Next?

Next session: [Session 3 – Prompting Techniques](03_prompting-techniques.md)

---

## Additional Resources

- **VS Code Documentation:** [code.visualstudio.com/docs](https://code.visualstudio.com/docs)
- **GitHub Copilot Guide:** [github.com/features/copilot](https://github.com/features/copilot)
- **Arduino IDE Setup:** [arduino.cc/en/Guide](https://arduino.cc/en/Guide)
- **Google Test Primer:** [github.com/google/googletest](https://github.com/google/googletest)
- **CMake Documentation:** [cmake.org/documentation](https://cmake.org/documentation)

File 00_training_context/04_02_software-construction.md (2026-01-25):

# Session 4.2: Implementation – Detailed Design & Code Generation

**Focus:** Detailed Design → Source Code

**Time:** ~30 minutes

## Part 1: Detailed Design

When is Detailed Design Really Necessary?

**Short answer:** Detailed Design is necessary when the gap between architecture and code is significant.

### Why Sequence Diagrams Are Critical

- ✅ Catches design flaws before coding
- ✅ Helps developers understand the execution flow without reading code
- ✅ Simplifies testing (test each sequence independently)
- ✅ Eases debugging (trace actual execution against expected sequence)
- ✅ Documents how layers coordinate (crucial for team handoffs)

**Create separate detailed design document when:**
- Architecture is vague on algorithm specifics
- Team members are unsure how to implement a component
- Complex state machines need visual walkthroughs
- Standards (IEC 61508, DO-178C, IEC 62304) mandate detailed design phase
- Cross-team coordination needed (unclear interfaces)
- Estimated code size > 5000 lines

**Skip detailed design if:**
- Architecture specifies all data structures and function signatures
- Algorithms are simple (linear ramp, debounce filter)
- Team understands design well enough to code directly
- Project timeline is tight and team is experienced

**Decision Tree**

```mermaid
graph TD
    A["<b>Is your architecture<br/>design detailed enough<br/>to code directly?</b><br/><br/>Example: Clear data structures,<br/>function signatures, state<br/>transitions, algorithms"] -->|Yes| B["<b>Can a developer start<br/>coding without asking<br/>clarifying questions?</b><br/><br/>Example: Knows exact PWM<br/>calculation, state entry/exit<br/>logic, error handling"]
    A -->|No| D["<b>⚠️ Create Detailed Design</b><br/>Document before coding<br/><br/>Focus on:<br/>- Algorithm pseudocode<br/>- Data structure layouts<br/>- Error handling logic<br/>- Edge cases"]
    
    B -->|Yes| C["<b>✅ Skip Detailed Design</b><br/>Go straight to code generation<br/>using architecture as blueprint<br/><br/>Example: This project"]
    B -->|No| D
    
    style A fill:#FFE6E6,stroke:#333,color:#000000
    style B fill:#FFE6E6,stroke:#333,color:#000000
    style C fill:#90EE90,stroke:#333,color:#000000
    style D fill:#FFD700,stroke:#333,color:#000000
```

### Key Elements of a Detailed Design

When you decide detailed design is necessary, include these elements:

| Element | Purpose | Example (Desk Automation) |
|---|---|---|
| **Data Structure Layouts** | Define exact memory layout, field ordering, sizes | `struct AppInput_t { bool btn_up; bool btn_down; bool btn_stop; bool limit; uint32_t elapsed_ms; }` |
| **Algorithm Pseudocode** | Step-by-step logic before code (not in code comments) | Linear PWM ramp: `pwm = (target_pwm * elapsed_ms) / 500` for 0–500 ms |
| **State Machine Diagram** | Visual state transitions with entry/exit actions | IDLE → RAISING (entry: start ramp), RAISING → IDLE (exit: stop ramp, decelerate) |
| **Sequence Diagrams** | Interaction between components over time | Main Loop calls DeskApp_task() → calls MotorControl_getRampedSpeed() → returns PWM → HAL_setMotorPWM() |
| **Error Handling Logic** | How to handle edge cases and faults | If stall timeout (2 sec at PWM ≥ 240), transition to FAULT; require STOP to reset |
| **Interface Specifications** | Exact function signatures, parameters, return types | `uint8_t MotorControl_getRampedSpeed(uint32_t elapsed_ms)` returns 0–255 linearly over 500 ms |
| **Timing Diagrams** | Critical timing constraints (latency, frequencies) | Button debounce: 50 ms hysteresis; Main loop: 10 ms cycle (100 Hz); Ramp: 500 ± 50 ms |
| **Decision Tables** | Complex conditionals in tabular form | State transitions table: From state, input → next state, action |
| **Risk & Edge Cases** | Known issues and mitigation | Risk: limit switch fails during RAISING → mitigation: 2-sec stall timeout catches blockage |

---

### Prompt to Generate Detailed Design (Copy & Paste)

**Use this prompt to generate a detailed design document:**

```
Generate a detailed design specification for the desk automation software system.

Review UPSTREAM ARTIFACTS AVAILABLE;

DETAILED DESIGN ELEMENTS TO INCLUDE:
- Data Structure Definitions
- State Machine Documentation
- Sequence Diagrams (Mermaid)
- Algorithm Pseudocode
- Class diagrams
- Class and Function Interface Specifications
- Timing Diagrams (ASCII or Mermaid Gantt)
- Interface Specifications (Function Contracts)
- Error Handling & Edge Cases
- Risk Assessment

FORMAT: Markdown document with sections above. Use Mermaid diagrams for state machine, sequence diagrams, and timing. Include pseudocode blocks. Provide detailed rationale for each design choice.

DELIVERABLE: A detailed design document that a developer can use to implement code without ambiguity. Add it under documentation directory.

```

**For this project:** 3 key sequences cover all use cases (RAISE, STOP, STALL).

## Part 2: Code Implementation

### Prompt for Source Code Generation (Copy & Paste)

```
TASK: Implement complete Arduino source code for standing desk motor controller based on upstream documentation.

UPSTREAM DOCUMENTATION TO REVIEW:
1. Software Architecture 
2. Software Requirements 
3. System Requirements 
4. ConOps
5. Detailed Design (if available) 

ARCHITECTURE ADHERENCE:
- Implement exactly 4 layers: Main Loop → DeskApp → MotorController → HAL (+ PinConfig file)
- DeskApp: State machine (IDLE, RAISING, LOWERING, FAULT) with deterministic transitions
- MotorController: PWM ramping (0→255 over 500±50ms), stall detection (2±0.2s timeout)
- HAL: GPIO abstraction (buttons, limit switch, motor PWM, LED), debouncing (50ms)
- Main Loop: Polling, task invocation, output dispatch (~100ms cycle)

FILE STRUCTURE (create all files under src):
1. pin_config.h
2. hal.h / hal.cpp — Hardware Abstraction Layer
3. motor_controller.h / motor_controller.cpp — Motor Control Logic
4. desk_app.h / desk_app.cpp — Application Control (State Machine)
5. desk_automation.ino — Main Loop (Arduino entry point)

CODING STANDARDS (industry best practices):
- Use const for immutable data (pin definitions, configuration)
- Use static for file-scope variables (avoid global pollution)
- Prefix all functions with module name (e.g., HAL_readButton, DeskApp_init)
- Add header guards (#ifndef HAL_H / #define HAL_H / #endif)
- Use enums for states, button types, LED colors (not magic numbers)
- Comment all public functions with purpose, parameters, return value
- Add file headers: filename, purpose, author/date (optional)
- Use meaningful variable names (debounceTimer, not dt; currentState, not cs)
- Avoid malloc/free (embedded constraint; use static allocation)
- Keep functions < 50 lines (single responsibility principle)
- Code must be correct, buildable, and warning-free
- Keep it simple: readable by unexperienced developers

REQUIREMENTS TRACEABILITY (verify each SWReq implemented)
BE AWARE TIMING AND RESOURCE CONSTRAINTS (validate in code)
OUTPUT LOCATION: Save all files under src directory

NOTES:
- Prioritize clarity over cleverness (code will be reviewed by others)
- Follow sequence diagrams exactly (Main Loop → DeskApp → MotorController → HAL → Hardware)
- DeskApp must be hardware-agnostic (no pinMode, digitalWrite, analogWrite calls in application layer)
- HAL is the only layer that directly interacts with lower-level APIS (e.g.: RTOS, MicroController libs, Arduino´s pinMode, digitalRead, analogWrite)
- Application layer entry points has API clearly defined through:
   - [APP_NAME]_Init(...) and [APP_NAME]_Task(&inputStruct, &outputStruct)
   - InputStruct: gathers all logical inputs needed from outside APP layer
   - OutputStruct: returns all logical outputs coming out of the APP Layer - These will be used by the integration/signal layer to call HAL and other target system functions.
   - Consider low big-O complexity algorithms

```

### Post generation:
- Check if it builds on arduino IDE.
- Refactor and re-work code as needed.
- The probably to be close to your ideal depends on how detailed the prompt was.

## Key Takeaways

- **Layer-by-layer implementation:** HAL → MotorControl → DeskApp → Main Loop (bottom-up coding)
- **Architecture drives code:** Every function traces back to architecture design
- **Compile early, compile often:** Catch errors incrementally, not all at once
- **Separation of concerns works:** Each layer has clear responsibility; easy to understand and modify
- **AI generates boilerplate fast:** But human review ensures correctness and alignment with design

---

**Next Step:** Proceed to [component verification](04_03_00_component-verification.md).

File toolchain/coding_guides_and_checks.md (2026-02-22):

# Coding Guidelines and Automated Checks for Safety-Critical Embedded Software

## Quick Start: Running Pipeline Analysis

**Run all automated rule checks:**

```bash
# Complete pipeline with all analysis modes (integration, test, static-analysis)
python toolchain/run-pipeline.py all

# Individual analysis modes
python toolchain/run-pipeline.py integration   # Build and integration tests
python toolchain/run-pipeline.py test          # Unit and component tests
python toolchain/run-pipeline.py static-analysis  # CPPCheck and custom rules

# Run ALL rules with automatic comprehensive summary report
python toolchain/pipeline_analysis.py rules-all --src-path src
# OUTPUT: results/all_rules_summary.md (comprehensive pass/fail/skip report)

# Individual rule checks
python toolchain/rules/rule_RULE-001_R1_1_no_goto.py src      # Check specific rule
python toolchain/rules/rule_RULE-028_R8_1_include_guards.py src
```

**Expected Output:**
- `[PASS]` - Rule compliance verified
- `[FAIL]` - Violations found (exit code 1)
- `[WARN]` - Warnings or advisory issues (exit code 0)
- `[SKIP]` - Check skipped (tool not available)
- **Summary Report:** `results/all_rules_summary.md` generated by `rules-all` command with detailed results table and pass/fail counts

**Current Coverage:** 80 total rules, 51 automated (64%)
- 🤖 Automated Scripts: 51 rules with pattern matching, AST analysis, and tool integration
- 🔍 Code Review: 29 rules requiring human judgment
- ⚠️ **Deprecated:** RULE-047 (test coverage via gcov - no longer performed)
- **See Rule Index below for complete list and automation method**

---

**Document Revision History:**

| Version | Date | Author | Changes |
|---|---|---|---|
| 1.0 | 2026-02-22 | A. Perico + A.I. | Initial version based on NASA Power of Ten |
| 1.1 | 2026-02-22 | A. Perico + A.I. | Added MISRA C:2012 and ISO 25119 rules with automation guidance |
| 1.2 | 2026-02-22 | A. Perico + A.I. | Performance optimizations, RULE-047 deprecation, summary report improvements |

**Approval:**

- [ ] Software Lead
- [ ] Safety Engineer  
- [ ] Quality Manager
--

**Project:** Automated Mechanical Desk Lift System  
**Compliance Standards:**
- ISO 25119 (Functional Safety for Agricultural and Forestry Machinery)
- ASPICE Level 2 (Automotive SPICE)
- MISRA C:2012 (Selected Rules)
- NASA/JPL "Power of Ten" Rules for Safety-Critical Code

**Reference Documents:**
- [NASA Power of Ten Rules](resources/nasa10rules.pdf)
- MISRA C:2012 Guidelines for the use of the C language in critical systems
- ISO 25119-3:2018 Software design and development requirements

**Last Updated:** February 22, 2026

---

## Table of Contents

- [Coding Guidelines and Automated Checks for Safety-Critical Embedded Software](#coding-guidelines-and-automated-checks-for-safety-critical-embedded-software)
  - [Quick Start: Running Pipeline Analysis](#quick-start-running-pipeline-analysis)
  - [Table of Contents](#table-of-contents)
  - [Rule Index (Unified IDs)](#rule-index-unified-ids)
  - [Introduction](#introduction)
    - [Why These Rules?](#why-these-rules)
    - [Scope](#scope)
    - [Enforcement](#enforcement)
  - [Rule 1: Simple Control Flow](#rule-1-simple-control-flow)
    - [Requirements](#requirements)
  - [Rule 2: Fixed Loop Bounds](#rule-2-fixed-loop-bounds)
    - [Requirements](#requirements-1)
  - [Rule 3: No Dynamic Memory Allocation](#rule-3-no-dynamic-memory-allocation)
    - [Requirements](#requirements-2)
  - [Rule 4: Short Functions](#rule-4-short-functions)
    - [Requirements](#requirements-3)
  - [Rule 5: Defensive Assertions](#rule-5-defensive-assertions)
    - [Requirements](#requirements-4)
  - [Rule 6: Minimal Variable Scope](#rule-6-minimal-variable-scope)
    - [Requirements](#requirements-5)
  - [Rule 7: Check Return Values](#rule-7-check-return-values)
    - [Requirements](#requirements-6)
  - [Rule 8: Limited Preprocessor Use](#rule-8-limited-preprocessor-use)
    - [Requirements](#requirements-7)
  - [Rule 9: Restricted Pointer Use](#rule-9-restricted-pointer-use)
    - [Requirements](#requirements-8)
  - [Rule 10: Aggressive Compiler Warnings and Static Analysis](#rule-10-aggressive-compiler-warnings-and-static-analysis)
    - [Requirements](#requirements-9)
  - [Project-Specific Guidelines](#project-specific-guidelines)
    - [Naming Conventions](#naming-conventions)
    - [Safety-Critical Code](#safety-critical-code)
    - [Testing Requirements](#testing-requirements)
  - [Rule 14: Code Quality Metrics](#rule-14-code-quality-metrics)
    - [Requirements](#requirements-10)
  - [MISRA C:2012 Compliance Rules](#misra-c2012-compliance-rules)
    - [Overview](#overview)
    - [Core MISRA C Rules for Safety-Critical Systems](#core-misra-c-rules-for-safety-critical-systems)
    - [MISRA Rule Categories](#misra-rule-categories)
  - [ISO 25119 Coding Requirements](#iso-25119-coding-requirements)
    - [ISO 25119-3 Software Design Rules](#iso-25119-3-software-design-rules)
    - [Defensive Programming (ISO 25119)](#defensive-programming-iso-25119)
  - [Automated Checking](#automated-checking)
    - [Comprehensive Automated Checks Table](#comprehensive-automated-checks-table)
    - [Automation Scripts Reference](#automation-scripts-reference)
    - [Manual Review Rules (Require human judgment)](#manual-review-rules-require-human-judgment)
  - [Appendix: Quick Reference](#appendix-quick-reference)
    - [Critical Rules (Must Never Violate)](#critical-rules-must-never-violate)
    - [Recommended Practices](#recommended-practices)
    - [Automated Checking Command](#automated-checking-command)
    - [Tool Configuration](#tool-configuration)
  - [Conclusion](#conclusion)

---

## Rule Index (Unified IDs)

This index assigns a unique, portable identifier to every rule in this document.

**Legend:**
- 🤖 **Automated Script:** Full automation available
- 🔍 **Code Review:** Manual review required  
- 📊 **Tool-Based:** Use external tools (compiler, cppcheck, gcov, etc.)
- 📝 **Pattern Match:** Simple grep/regex pattern matching available

| Unified ID | Original ID | Rule Title | Automation | Method |
|---|---|---|---|---|
| RULE-001 | R1.1 | No goto statements | 🤖 | [rule_RULE-001_R1_1_no_goto.py](../toolchain/rules/rule_RULE-001_R1_1_no_goto.py) |
| RULE-002 | R1.2 | No setjmp/longjmp | 🤖 | [rule_RULE-002_R1_2_no_setjmp_longjmp.py](../toolchain/rules/rule_RULE-002_R1_2_no_setjmp_longjmp.py) |
| RULE-003 | R1.3 | No recursion | 🤖 | [rule_RULE-003_R1_3_no_recursion.py](../toolchain/rules/rule_RULE-003_R1_3_no_recursion.py) |
| RULE-004 | R1.4 | Single entry/exit | 🔍 | Code review - verify each function has one entry point and exit sequence |
| RULE-005 | R2.1 | Bounded loops | 🔍 | Loop termination proof needed; examine loop counters and bounds |
| RULE-006 | R2.2 | Loop counter limits | 🔍 | Code review - verify loop variables have explicit bounds |
| RULE-007 | R2.3 | No while(true) except main | 🤖 | [rule_RULE-007_R2_3_no_while_true.py](../toolchain/rules/rule_RULE-007_R2_3_no_while_true.py) |
| RULE-008 | R2.4 | Loop invariants documented | 🔍 | Code review - check comments document loop invariants for complex loops |
| RULE-009 | R3.1 | No malloc/calloc/realloc/free | 🤖 | [rule_RULE-009_R3_1_no_malloc_free.py](../toolchain/rules/rule_RULE-009_R3_1_no_malloc_free.py) |
| RULE-010 | R3.2 | Avoid hidden dynamic allocation | 🔍 | Library audit + code review; check for implicit allocation in dependencies |
| RULE-011 | R3.4 | Stack size limits | 🤖 | [rule_RULE-011_R3_4_stack_limits.py](../toolchain/rules/rule_RULE-011_R3_4_stack_limits.py) |
| RULE-012 | R4.1 | Function length limit | 🤖 | [rule_RULE-012_R4_1_function_length.py](../toolchain/rules/rule_RULE-012_R4_1_function_length.py) |
| RULE-013 | R4.2 | Single responsibility | 🔍 | Design review - verify each function has one clear purpose |
| RULE-014 | R4.3 | Cyclomatic complexity <= 10 | 🤖 | [rule_RULE-014_R4_3_complexity.py](../toolchain/rules/rule_RULE-014_R4_3_complexity.py) |
| RULE-015 | R5.1 | Assertion density | 🤖 | [rule_RULE-053_R14_5_assertion_density.py](../toolchain/rules/rule_RULE-053_R14_5_assertion_density.py) (see R14.5) |
| RULE-016 | R5.2 | Precondition checks | 🔍 | Code review - verify functions validate input parameters at entry |
| RULE-017 | R5.3 | Invariant checks | 🔍 | Code review - verify critical invariants guarded by assertions |
| RULE-018 | R5.4 | Assertions in release builds | 🤖 | [rule_RULE-018_R5_4_ndebug.py](../toolchain/rules/rule_RULE-018_R5_4_ndebug.py) |
| RULE-019 | R5.5 | No side effects in assertions | 🤖 | [rule_RULE-019_R5_5_assert_side_effects.py](../toolchain/rules/rule_RULE-019_R5_5_assert_side_effects.py) |
| RULE-020 | R6.1 | Local scope preferred | 🔍 | Code review - verify variables declared in innermost scope possible |
| RULE-021 | R6.2 | Minimize global variables | 🤖 | [rule_RULE-021_R6_2_minimize_globals.py](../toolchain/rules/rule_RULE-021_R6_2_minimize_globals.py) |
| RULE-022 | R6.3 | Static variables documented | 🤖 | [rule_RULE-022_R6_3_static_documented.py](../toolchain/rules/rule_RULE-022_R6_3_static_documented.py) |
| RULE-023 | R6.4 | Initialize at declaration | 🤖 | [rule_RULE-023_R6_4_init_at_decl.py](../toolchain/rules/rule_RULE-023_R6_4_init_at_decl.py) |
| RULE-024 | R7.1 | Check all return values | 🤖 | [rule_RULE-024_R7_1_unused_return.py](../toolchain/rules/rule_RULE-024_R7_1_unused_return.py) |
| RULE-025 | R7.2 | Parameter validation | 🔍 | Code review - verify public functions check parameters at entry |
| RULE-026 | R7.3 | Pointer parameter checks | 🤖 | [rule_RULE-026_R7_3_null_checks.py](../toolchain/rules/rule_RULE-026_R7_3_null_checks.py) |
| RULE-027 | R7.4 | Error propagation | 🔍 | Code review - verify error codes propagate up call chain correctly |
| RULE-028 | R8.1 | Include guards only | 🤖 | [rule_RULE-028_R8_1_include_guards.py](../toolchain/rules/rule_RULE-028_R8_1_include_guards.py) |
| RULE-029 | R8.2 | No function-like macros | 🤖 | [rule_RULE-029_R8_2_no_function_macros.py](../toolchain/rules/rule_RULE-029_R8_2_no_function_macros.py) |
| RULE-030 | R8.3 | Named constants only | 🤖 | [rule_RULE-030_R8_3_named_constants.py](../toolchain/rules/rule_RULE-030_R8_3_named_constants.py) |
| RULE-031 | R8.4 | Conditional compilation for platform only | 🤖 | [rule_RULE-031_R8_4_conditional_compile.py](../toolchain/rules/rule_RULE-031_R8_4_conditional_compile.py) |
| RULE-032 | R9.1 | Prefer non-NULL interfaces | 🔍 | Code review - document assumptions about NULL parameters |
| RULE-033 | R9.2 | No pointer arithmetic | 🤖 | [rule_RULE-033_R9_2_no_pointer_arith.py](../toolchain/rules/rule_RULE-033_R9_2_no_pointer_arith.py) |
| RULE-034 | R9.3 | No function pointers | 🤖 | [rule_RULE-034_R9_3_no_function_pointers.py](../toolchain/rules/rule_RULE-034_R9_3_no_function_pointers.py) |
| RULE-035 | R9.4 | No multi-level pointers | 🤖 | [rule_RULE-035_R9_4_no_multilevel_pointers.py](../toolchain/rules/rule_RULE-035_R9_4_no_multilevel_pointers.py) |
| RULE-036 | R9.5 | No opaque ownership transfers | 🔍 | Design review - verify pointer ownership clearly documented in contracts |
| RULE-037 | R10.1 | Required compiler flags | 🤖 | [rule_RULE-037_R10_1_compiler_flags.py](../toolchain/rules/rule_RULE-037_R10_1_compiler_flags.py) |
| RULE-038 | R10.2 | Zero warnings policy | 🤖 | [rule_RULE-038_R10_2_zero_warnings.py](../toolchain/rules/rule_RULE-038_R10_2_zero_warnings.py) |
| RULE-039 | R10.3 | Run static analysis | 🤖 | [rule_RULE-039_R10_3_cppcheck_run.py](../toolchain/rules/rule_RULE-039_R10_3_cppcheck_run.py) |
| RULE-040 | R10.4 | Zero static analysis errors | 🤖 | [rule_RULE-040_R10_4_cppcheck_clean.py](../toolchain/rules/rule_RULE-040_R10_4_cppcheck_clean.py) |
| RULE-041 | R10.5 | MISRA C:2012 compliance (pattern-based) | 🤖 | [rule_RULE-041_R10_5_misra_compliance.py](../toolchain/rules/rule_RULE-041_R10_5_misra_compliance.py) |
| RULE-042 | R11.1 | Function naming | 🤖 | [rule_RULE-042_R11_1_function_naming.py](../toolchain/rules/rule_RULE-042_R11_1_function_naming.py) |
| RULE-043 | R11.2 | Variable naming | 🤖 | [rule_RULE-043_R11_2_variable_naming.py](../toolchain/rules/rule_RULE-043_R11_2_variable_naming.py) |
| RULE-044 | R11.3 | Type naming | 🤖 | [rule_RULE-044_R11_3_type_naming.py](../toolchain/rules/rule_RULE-044_R11_3_type_naming.py) |
| RULE-045 | R12.1 | Safety markers | 🤖 | [rule_RULE-045_R12_1_safety_markers.py](../toolchain/rules/rule_RULE-045_R12_1_safety_markers.py) |
| RULE-046 | R12.2 | Fail-safe defaults | 🔍 | Code review - verify safe state initialization in all structures |
| RULE-047 | R13.1 | ~~Unit test coverage~~ (DEPRECATED - gcov not used) | ⚠️ | (removed) |
| RULE-048 | R13.2 | Test naming | 🤖 | [rule_RULE-048_R13_2_test_naming.py](../toolchain/rules/rule_RULE-048_R13_2_test_naming.py) |
| RULE-049 | R14.1 | Function length limit (60 lines) | 🤖 | [rule_RULE-049_R14_1_function_length.py](../toolchain/rules/rule_RULE-049_R14_1_function_length.py) |
| RULE-050 | R14.2 | Function parameters limit (4 max) | 🤖 | [rule_RULE-050_R14_2_parameter_count.py](../toolchain/rules/rule_RULE-050_R14_2_parameter_count.py) |
| RULE-051 | R14.3 | Nesting depth limit (4 levels) | 🤖 | [rule_RULE-051_R14_3_nesting_depth.py](../toolchain/rules/rule_RULE-051_R14_3_nesting_depth.py) |
| RULE-052 | R14.4 | File length limit (800 lines) | 🤖 | [rule_RULE-052_R14_4_file_length.py](../toolchain/rules/rule_RULE-052_R14_4_file_length.py) |
| RULE-053 | R14.5 | Assertion density minimum (2 per function) | 🤖 | [rule_RULE-053_R14_5_assertion_density.py](../toolchain/rules/rule_RULE-053_R14_5_assertion_density.py) |
| RULE-054 | MISRA-1.3 | No undefined/critical unspecified behavior | 🤖 | [rule_RULE-054_MISRA_1_3_cppcheck.py](../toolchain/rules/rule_RULE-054_MISRA_1_3_cppcheck.py) |
| RULE-055 | MISRA-2.1 | No unreachable code | 🤖 | [rule_RULE-055_MISRA_2_1_unreachable.py](../toolchain/rules/rule_RULE-055_MISRA_2_1_unreachable.py) |
| RULE-056 | MISRA-2.2 | No dead code | 🤖 | [rule_RULE-056_MISRA_2_2_dead_code.py](../toolchain/rules/rule_RULE-056_MISRA_2_2_dead_code.py) |
| RULE-057 | MISRA-8.1 | Types explicitly specified | 🤖 | [rule_RULE-057_MISRA_8_1_compiler_flags.py](../toolchain/rules/rule_RULE-057_MISRA_8_1_compiler_flags.py) |
| RULE-058 | MISRA-8.3 | Consistent function declarations (cppcheck) | 🤖 | [rule_RULE-058_MISRA_8_3_function_consistency.py](../toolchain/rules/rule_RULE-058_MISRA_8_3_function_consistency.py) |
| RULE-059 | MISRA-9.1 | Initialize automatic variables | 🤖 | [rule_RULE-059_MISRA_9_1_uninit.py](../toolchain/rules/rule_RULE-059_MISRA_9_1_uninit.py) |
| RULE-060 | MISRA-10.1 | Appropriate essential types | 🤖 | [rule_RULE-060_MISRA_10_1_types.py](../toolchain/rules/rule_RULE-060_MISRA_10_1_types.py) |
| RULE-061 | MISRA-10.3 | No narrowing assignments | 🤖 | [rule_RULE-061_MISRA_10_3_narrowing.py](../toolchain/rules/rule_RULE-061_MISRA_10_3_narrowing.py) |
| RULE-062 | MISRA-10.4 | Same essential type category | 🤖 | [rule_RULE-062_MISRA_10_4_conversion_warnings.py](../toolchain/rules/rule_RULE-062_MISRA_10_4_conversion_warnings.py) |
| RULE-063 | MISRA-11.3 | No object pointer casting | 🤖 | [rule_RULE-063_MISRA_11_3_pointer_cast.py](../toolchain/rules/rule_RULE-063_MISRA_11_3_pointer_cast.py) |
| RULE-064 | MISRA-12.1 | Explicit operator precedence | 🤖 | [rule_RULE-064_MISRA_12_1_operator_precedence.py](../toolchain/rules/rule_RULE-064_MISRA_12_1_operator_precedence.py) |
| RULE-065 | MISRA-13.2 | Single side effect per expression | 🤖 | [rule_RULE-065_MISRA_13_2_side_effects.py](../toolchain/rules/rule_RULE-065_MISRA_13_2_side_effects.py) |
| RULE-066 | MISRA-14.3 | No invariant control expressions | 🤖 | [rule_RULE-066_MISRA_14_3_invariant_control.py](../toolchain/rules/rule_RULE-066_MISRA_14_3_invariant_control.py) |
| RULE-067 | MISRA-16.3 | Switch clauses end with break | 🤖 | [rule_RULE-067_MISRA_16_3_switch_break.py](../toolchain/rules/rule_RULE-067_MISRA_16_3_switch_break.py) |
| RULE-068 | MISRA-17.7 | Use return values | 🤖 | [rule_RULE-068_MISRA_17_7_return_used.py](../toolchain/rules/rule_RULE-068_MISRA_17_7_return_used.py) |
| RULE-069 | MISRA-18.1 | Pointer arithmetic within bounds | 🤖 | [rule_RULE-069_MISRA_18_1_pointer_bounds.py](../toolchain/rules/rule_RULE-069_MISRA_18_1_pointer_bounds.py) |
| RULE-070 | MISRA-21.3 | No dynamic allocation | 🤖 | [rule_RULE-070_MISRA_21_3_no_malloc.py](../toolchain/rules/rule_RULE-070_MISRA_21_3_no_malloc.py) |
| RULE-071 | MISRA-21.6 | No standard I/O functions | 🤖 | [rule_RULE-071_MISRA_21_6_no_stdio.py](../toolchain/rules/rule_RULE-071_MISRA_21_6_no_stdio.py) |
| RULE-072 | ISO-001 | Requirement traceability | 🤖 | [rule_RULE-072_ISO_001_traceability.py](../toolchain/rules/rule_RULE-072_ISO_001_traceability.py) |
| RULE-073 | ISO-002 | Defensive programming | 🤖 | [rule_RULE-073_ISO_002_assert_density.py](../toolchain/rules/rule_RULE-073_ISO_002_assert_density.py) |
| RULE-074 | ISO-003 | Software diversity | 🔍 | Architectural review - verify independent safety checks in critical functions |
| RULE-075 | ISO-004 | Fail-safe behavior | 🔍 | Error handling review - verify all errors lead to safe state |
| RULE-076 | ISO-005 | Watchdog monitoring | 🔍 | Code review - verify watchdog refresh calls in task loop |
| RULE-077 | ISO-006 | Memory integrity checks | 🔍 | Code review - verify CRC/parity on safety-critical data structures |
| RULE-078 | ISO-007 | Plausibility checks | 🔍 | Code review - verify sensor outputs have range/rate validation |
| RULE-079 | ISO-008 | Range checking | 🔍 | Code review - verify function parameters validated at entry |
| RULE-080 | ISO-009 | State transition validity | 🔍 | State machine review - verify only legal transitions allowed |
| RULE-081 | ISO-010 | Overflow prevention | 🔍 | Code review + compiler: `-Wconversion` helps identify overflow risks

## Introduction

This document defines mandatory coding standards for the Automated Mechanical Desk Lift System. These rules are derived from NASA/JPL's "Power of Ten" rules for developing safety-critical code, adapted for our embedded C/C++ control system.

**Portability Note:** These guidelines are written to be portable and usable in both C and C++ projects. The rules focus primarily on C, and any C++-specific guidance has been removed when it does not apply cleanly to C.

### Why These Rules?

Safety-critical embedded systems require:
- **Predictability:** Code behavior must be deterministic and analyzable
- **Verifiability:** All code paths must be testable and provable
- **Reliability:** No undefined behavior or runtime failures
- **Maintainability:** Code must be understandable by all team members

### Scope

These rules apply to all C and C++ source code in:
- `src/*.c` and `src/*.cpp` - Application logic
- `src/*.h` - Public interfaces
- Motor control algorithms
- Safety-critical functions (marked with `// SAFETY-CRITICAL`)

### Enforcement

Rules are enforced through:
1. **Automated Checks:** Static analysis (cppcheck), compiler warnings (-Wall -Wextra -Werror)
2. **Code Reviews:** All code must pass peer review
3. **CI/CD Pipeline:** Automated checks on every commit
4. **Manual Verification:** Complex rules verified during code review

---

## Rule 1: Simple Control Flow

**Principle:** Restrict all code to very simple control flow constructs to ensure code is easy to analyze and verify.

### Requirements

**R1.1 - No goto Statements**
- **Rule:** Never use `goto` statements
- **Rationale:** `goto` creates unpredictable control flow and makes analysis difficult
- **Check Method:** Automated (grep, cppcheck)
- **Severity:** CRITICAL

```c
// ❌ PROHIBITED
void bad_function() {
    if (error) goto error_handler;
    // ...
    error_handler:
        cleanup();
}

// ✅ CORRECT
void good_function() {
    if (error) {
        cleanup();
        return;
    }
    // ...
}
```

**R1.2 - No setjmp/longjmp**
- **Rule:** Never use `setjmp()` or `longjmp()`
- **Rationale:** Non-local jumps break stack unwinding and RAII
- **Check Method:** Automated (grep)
- **Severity:** CRITICAL

**R1.3 - Limited Recursion**
- **Rule:** Recursion is prohibited in production code
- **Rationale:** Unbounded stack usage in embedded systems
- **Exception:** Test code may use recursion if stack depth is proven bounded
- **Check Method:** Manual review, static analysis
- **Severity:** CRITICAL

```c
// ❌ PROHIBITED - Recursion
int fibonacci_recursive(int n) {
    if (n <= 1) return n;
    return fibonacci_recursive(n-1) + fibonacci_recursive(n-2);
}

// ✅ CORRECT - Iterative
int fibonacci_iterative(int n) {
    if (n <= 1) return n;
    int prev = 0, curr = 1;
    for (int i = 2; i <= n; i++) {
        int next = prev + curr;
        prev = curr;
        curr = next;
    }
    return curr;
}
```

**R1.4 - Single Entry/Exit**
- **Rule:** Functions should have single entry and single exit point where practical
- **Rationale:** Easier to reason about function behavior and resource cleanup
- **Exception:** Early `return` for error conditions is acceptable
- **Check Method:** Code review
- **Severity:** RECOMMENDED

```c
// ✅ ACCEPTABLE - Early return for errors
ErrorCode process_command(Command cmd) {
    if (!cmd.is_valid()) {
        return ERR_INVALID_COMMAND;  // Early exit OK
    }
    
    // Main processing
    ErrorCode result = do_work(cmd);
    
    return result;  // Single exit for success path
}
```

---

## Rule 2: Fixed Loop Bounds

**Principle:** All loops must have a fixed upper bound that can be statically verified.

### Requirements

**R2.1 - Bounded Loops**
- **Rule:** Every loop must have a demonstrably bounded iteration count
- **Rationale:** Prevent infinite loops and ensure worst-case execution time (WCET) is calculable
- **Check Method:** Code review, static analysis
- **Severity:** CRITICAL

```c
// ❌ PROHIBITED - Unbounded loop
while (sensor_active()) {  // Could run forever
    read_sensor();
}

// ✅ CORRECT - Fixed iterations
const uint8_t MAX_RETRIES = 3;
for (uint8_t i = 0; i < MAX_RETRIES && sensor_active(); i++) {
    read_sensor();
}

// ✅ CORRECT - Timeout bound
const uint32_t TIMEOUT_MS = 100;
uint32_t start_time = HAL_get_time_ms();
while ((HAL_get_time_ms() - start_time) < TIMEOUT_MS && sensor_active()) {
    read_sensor();
}
```

**R2.2 - Loop Counter Limits**
- **Rule:** Loop counters must use fixed-size types with explicit upper bounds
- **Rationale:** Prevent overflow and ensure bounds are clear
- **Check Method:** Code review
- **Severity:** MANDATORY

```c
// ❌ POOR - Implicit bound
for (int i = 0; i < array_size; i++) {  // 'int' size is platform-dependent
    process(array[i]);
}

// ✅ CORRECT - Explicit bound
const uint8_t ARRAY_SIZE = 10;
for (uint8_t i = 0; i < ARRAY_SIZE; i++) {
    process(array[i]);
}
```

**R2.3 - No while(true)**
- **Rule:** `while(true)` or `for(;;)` loops prohibited except in main task loop
- **Rationale:** Infinite loops acceptable only at top-level task structure
- **Exception:** Main control loop in `DeskApp_task()` or interrupt handlers
- **Check Method:** Automated (grep)
- **Severity:** CRITICAL

```c
// ✅ ACCEPTABLE - Main task loop only
void DeskApp_task() {
    while (true) {  // Top-level control loop OK
        read_inputs();
        update_state();
        control_outputs();
        delay(TASK_PERIOD_MS);
    }
}

// ❌ PROHIBITED - Infinite loop in function
void wait_for_sensor() {
    while (true) {  // Never do this
        if (sensor_ready()) break;
    }
}

// ✅ CORRECT - Bounded wait
bool wait_for_sensor_timeout(uint32_t timeout_ms) {
    uint32_t start = HAL_get_time_ms();
    while ((HAL_get_time_ms() - start) < timeout_ms) {
        if (sensor_ready()) return true;
    }
    return false;  // Timeout
}
```

**R2.4 - Loop Invariants**
- **Rule:** Complex loops must document their invariants
- **Rationale:** Helps verify correctness and aids maintenance
- **Check Method:** Code review
- **Severity:** RECOMMENDED

```c
// ✅ GOOD - Documented invariant
// Loop invariant: 0 <= i < BUFFER_SIZE and sum contains sum of buffer[0..i-1]
uint32_t sum = 0;
for (uint8_t i = 0; i < BUFFER_SIZE; i++) {
    sum += buffer[i];
}
```

---

## Rule 3: No Dynamic Memory Allocation

**Principle:** Do not use dynamic memory allocation (heap) after system initialization.

### Requirements

**R3.1 - No malloc/free**
- **Rule:** Prohibited: `malloc()`, `calloc()`, `realloc()`, `free()`
- **Rationale:** Fragmentation, non-deterministic timing, allocation failures
- **Check Method:** Automated (grep, static analysis)
- **Severity:** CRITICAL

**R3.2 - Avoid Hidden Dynamic Allocation**
- **Rule:** Do not use libraries or APIs that allocate memory implicitly at runtime
- **Rationale:** Hidden allocation undermines predictability and timing
- **Check Method:** Code review, static analysis
- **Severity:** MANDATORY

**R3.4 - Stack Size Limits**
- **Rule:** Stack usage per function must not exceed 512 bytes
- **Rationale:** Limited stack space in embedded systems (typically 2-8 KB total)
- **Check Method:** Static analysis, manual review
- **Severity:** MANDATORY

```c
// ❌ PROHIBITED - Excessive stack usage
void bad_function() {
    uint8_t large_buffer[2048];  // 2KB on stack - too large
    process(large_buffer);
}

// ✅ CORRECT - Static storage for large buffers
static uint8_t large_buffer[2048];  // Stored in .bss, not stack
void good_function() {
    process(large_buffer);
}
```

---

## Rule 4: Short Functions

**Principle:** Limit function length to a single printed page (60 lines of code).

### Requirements

**R4.1 - Function Length Limit**
- **Rule:** Functions must not exceed 60 lines of code (excluding comments and blank lines)
- **Rationale:** Short functions are easier to understand, test, and verify
- **Check Method:** Automated (line counting script)
- **Severity:** MANDATORY

```c
// ❌ POOR - Function too long (>60 lines)
// Split into smaller functions

// ✅ CORRECT - Functions under 60 lines
void update_motor_state() {  // ~20 lines
    read_sensors();
    calculate_control();
    apply_outputs();
}

void read_sensors() {  // ~15 lines
    button_state = read_buttons();
    limit_state = read_limits();
    current = read_motor_current();
}
```

**R4.2 - Single Responsibility**
- **Rule:** Each function should do one thing and do it well
- **Rationale:** Supports modularity and testability
- **Check Method:** Code review
- **Severity:** RECOMMENDED

**R4.3 - Function Complexity**
- **Rule:** Cyclomatic complexity must not exceed 10
- **Rationale:** High complexity indicates need for decomposition
- **Check Method:** Static analysis (cppcheck --enable=all)
- **Severity:** MANDATORY

---

## Rule 5: Defensive Assertions

**Principle:** Use assertions liberally to check assumptions and preconditions.

### Requirements

**R5.1 - Assertion Density**
- **Rule:** Use minimum 2 assertions per function on average
- **Rationale:** Defensive programming catches errors early
- **Check Method:** Manual review, automated counting
- **Severity:** RECOMMENDED

**R5.2 - Precondition Checks**
- **Rule:** All public functions must validate input parameters
- **Rationale:** Protect against invalid inputs
- **Check Method:** Code review
- **Severity:** MANDATORY

```c
// ✅ CORRECT - Parameter validation
void MotorController_set_direction(MotorDirection dir) {
    // Precondition: direction must be valid
    assert(dir == DIR_FORWARD || dir == DIR_REVERSE || dir == DIR_STOP);
    
    // Precondition: motor must be initialized
    assert(motor_initialized);
    
    // Function implementation
    current_direction = dir;
}
```

**R5.3 - Invariant Checks**
- **Rule:** Safety-critical functions must assert invariants
- **Rationale:** Detect corruption and violated assumptions
- **Check Method:** Code review
- **Severity:** CRITICAL (for safety-critical code)

```c
// SAFETY-CRITICAL
void DeskApp_update_state(DeskState* state) {
    // Invariant: state pointer must be valid
    assert(state != NULL);
    
    // Invariant: state must be in valid range
    assert(state->current >= STATE_IDLE && state->current <= STATE_ERROR);
    
    // Function implementation
    // ...
    
    // Post-condition: new state must be valid
    assert(state->current >= STATE_IDLE && state->current <= STATE_ERROR);
}
```

**R5.4 - Assertions in Release Builds**
- **Rule:** Safety-critical assertions must remain active in release builds
- **Rationale:** Safety checks should never be disabled
- **Implementation:** Use custom `SAFETY_ASSERT()` macro
- **Check Method:** Code review
- **Severity:** CRITICAL

```c
// ✅ CORRECT - Safety assertions always active
#define SAFETY_ASSERT(condition) \
    do { \
        if (!(condition)) { \
            HAL_enter_safe_state(); \
            while(1); /* Halt system */ \
        } \
    } while(0)

// SAFETY-CRITICAL
void apply_motor_power(uint8_t pwm) {
    SAFETY_ASSERT(pwm <= MAX_PWM_VALUE);  // Never disabled
    HAL_set_motor_pwm(pwm);
}
```

**R5.5 - No Side Effects in Assertions**
- **Rule:** Assertion conditions must not have side effects
- **Rationale:** If assertions are disabled, behavior must not change
- **Check Method:** Code review
- **Severity:** MANDATORY

```c
// ❌ PROHIBITED - Side effect in assertion
assert(read_sensor() > 0);  // Reads sensor as side effect

// ✅ CORRECT - No side effect
int sensor_value = read_sensor();
assert(sensor_value > 0);
```

---

## Rule 6: Minimal Variable Scope

**Principle:** Declare data objects at the smallest possible scope.

### Requirements

**R6.1 - Local Scope Preferred**
- **Rule:** Declare variables in the innermost scope where they are needed
- **Rationale:** Reduces coupling, prevents unintended access
- **Check Method:** Code review
- **Severity:** MANDATORY

```c
// ❌ POOR - Unnecessarily broad scope
void process_data() {
    int i, j, k;  // Declared at top
    uint8_t temp;
    
    for (i = 0; i < 10; i++) {
        // ...
    }
    
    for (j = 0; j < 5; j++) {  // j only used here
        // ...
    }
}

// ✅ CORRECT - Minimal scope
void process_data() {
    for (int i = 0; i < 10; i++) {  // i scoped to loop
        // ...
    }
    
    for (int j = 0; j < 5; j++) {  // j scoped to loop
        // ...
    }
}
```

**R6.2 - Minimize Global Variables**
- **Rule:** Global variables must be justified and documented
- **Rationale:** Globals create hidden coupling and complicate testing
- **Check Method:** Manual review
- **Severity:** MANDATORY

```c
// ❌ AVOID - Global state
int motor_pwm;  // Global, accessed from anywhere

// ✅ BETTER - Encapsulated in a module
static uint8_t motor_pwm = 0;

uint8_t MotorController_get_pwm(void) { return motor_pwm; }
void MotorController_set_pwm(uint8_t pwm) { motor_pwm = pwm; }
```

**R6.3 - Static Variables Documentation**
- **Rule:** Static variables must have comment explaining why static
- **Rationale:** Persistent state should be explicit and justified
- **Check Method:** Code review
- **Severity:** RECOMMENDED

```c
// ✅ CORRECT - Documented static
void count_calls() {
    // Static used to maintain call count across invocations
    // for diagnostic purposes only - not safety-critical
    static uint32_t call_count = 0;
    call_count++;
}
```

**R6.4 - Initialization at Declaration**
- **Rule:** Variables should be initialized at point of declaration
- **Rationale:** Prevents use of uninitialized variables
- **Check Method:** Compiler warnings (-Wuninitialized)
- **Severity:** MANDATORY

```c
// ❌ POOR - Uninitialized
uint8_t status;
// ... many lines of code
status = read_status();  // Could forget to initialize

// ✅ CORRECT - Initialize at declaration
uint8_t status = read_status();
```

---

## Rule 7: Check Return Values

**Principle:** Check the return value of all non-void functions, and check validity of parameters.

### Requirements

**R7.1 - Check All Return Values**
- **Rule:** Return value of every non-void function must be checked or explicitly ignored
- **Rationale:** Errors must not be silently ignored
- **Check Method:** Compiler warnings (-Wunused-result), code review
- **Severity:** CRITICAL

```c
// ❌ PROHIBITED - Ignored return value
read_sensor();  // Returns error code, but ignored

// ✅ CORRECT - Check return value
ErrorCode err = read_sensor();
if (err != ERR_OK) {
    handle_error(err);
}

// ✅ ACCEPTABLE - Explicitly void cast if truly don't care
(void)diagnostic_function();  // Explicitly ignored
```

**R7.2 - Parameter Validation**
- **Rule:** All function parameters must be validated
- **Rationale:** Protect against invalid inputs
- **Check Method:** Code review
- **Severity:** MANDATORY

```c
// ✅ CORRECT - Validate all parameters
ErrorCode set_motor_speed(uint8_t speed_percent) {
    // Validate parameter range
    if (speed_percent > 100) {
        return ERR_INVALID_PARAMETER;
    }
    
    // Parameter is valid, proceed
    motor_pwm = (speed_percent * MAX_PWM) / 100;
    return ERR_OK;
}
```

**R7.3 - Pointer Parameter Checks**
- **Rule:** All pointer parameters must be checked for NULL
- **Rationale:** Dereferencing NULL causes crash
- **Check Method:** Code review, static analysis
- **Severity:** CRITICAL

```c
// ✅ CORRECT - NULL pointer check
void process_buffer(const uint8_t* buffer, uint8_t length) {
    if (buffer == NULL) {
        return;  // Or handle error appropriately
    }
    
    if (length == 0) {
        return;  // Validate all parameters
    }
    
    // Safe to use buffer
    for (uint8_t i = 0; i < length; i++) {
        process_byte(buffer[i]);
    }
}
```

**R7.4 - Error Propagation**
- **Rule:** Errors must be propagated to caller or handled locally
- **Rationale:** No error should be lost
- **Check Method:** Code review
- **Severity:** MANDATORY

```c
// ✅ CORRECT - Error propagation
ErrorCode read_and_process() {
    ErrorCode err = read_sensor();
    if (err != ERR_OK) {
        return err;  // Propagate error to caller
    }
    
    err = process_data();
    if (err != ERR_OK) {
        return err;  // Propagate error
    }
    
    return ERR_OK;
}
```

---

## Rule 8: Limited Preprocessor Use

**Principle:** Limit preprocessor use to file inclusion and simple conditional compilation.

### Requirements

**R8.1 - Include Guards Only**
- **Rule:** Prefer `#pragma once` or include guards over complex preprocessor logic
- **Rationale:** Simplicity and portability
- **Check Method:** Code review
- **Severity:** MANDATORY

```c
// ✅ CORRECT - Include guard
#ifndef MOTOR_CONTROLLER_H
#define MOTOR_CONTROLLER_H

// Header content

#endif  // MOTOR_CONTROLLER_H

// ✅ ALSO CORRECT - Pragma once (simpler)
#pragma once

// Header content
```

**R8.2 - No Function-Like Macros**
- **Rule:** Prohibited: Function-like macros (except assertions)
- **Rationale:** Macros don't respect scope, type safety, or debugger
- **Exception:** Assertions and compile-time constants
- **Check Method:** Code review
- **Severity:** MANDATORY

```c
// ❌ PROHIBITED - Function-like macro
#define MAX(a, b) ((a) > (b) ? (a) : (b))  // Type-unsafe, evaluates args twice

// ✅ CORRECT - Inline function (C99+)
static inline int max_int(int a, int b) {
    return (a > b) ? a : b;
}
```

**R8.3 - Named Constants Only**
- **Rule:** Macros for constants only, with clear names
- **Rationale:** Constants are acceptable use of preprocessor
- **Check Method:** Code review
- **Severity:** RECOMMENDED

```c
// ✅ ACCEPTABLE - Named constants
#define MAX_BUFFER_SIZE 256
#define TASK_PERIOD_MS  10

// ✅ BETTER - Const variables
static const uint8_t MAX_BUFFER_SIZE = 256;
static const uint8_t TASK_PERIOD_MS = 10;
```

**R8.4 - Conditional Compilation**
- **Rule:** Conditional compilation only for platform/configuration
- **Rationale:** Minimize #ifdef complexity
- **Check Method:** Code review
- **Severity:** RECOMMENDED

```c
// ✅ ACCEPTABLE - Platform-specific
#ifdef TESTENVIRONMENT
    #include "HALMock.h"
#else
    #include <Arduino.h>
#endif

// ❌ AVOID - Logic in preprocessor
#ifdef FEATURE_X
    void do_x() { /* ... */ }
#else
    void do_x() { /* different impl */ }
#endif

// ✅ BETTER - Runtime logic
void do_x() {
    if (feature_x_enabled) {
        // Feature X implementation
    } else {
        // Alternative implementation
    }
}
```

---

## Rule 9: Restricted Pointer Use

**Principle:** Limit pointer use to minimize risk of errors.

### Requirements

**R9.1 - Prefer Non-NULL Interfaces Where Available**
- **Rule:** Prefer APIs that cannot accept NULL when the language supports it
- **Rationale:** Reduces null-dereference risk
- **Check Method:** Code review
- **Severity:** RECOMMENDED
- **Applicability:** C and C++

**R9.2 - No Pointer Arithmetic**
- **Rule:** Pointer arithmetic prohibited except for array indexing
- **Rationale:** Easy to make off-by-one errors
- **Exception:** Array traversal with bounds checking
- **Check Method:** Code review
- **Severity:** MANDATORY

```c
// ❌ PROHIBITED - Pointer arithmetic
uint8_t* p = buffer;
for (int i = 0; i < size; i++) {
    *(p + i) = 0;  // Pointer arithmetic
}

// ✅ CORRECT - Array indexing
for (int i = 0; i < size; i++) {
    buffer[i] = 0;  // Clear and safe
}
```

**R9.3 - No Function Pointers**
- **Rule:** Function pointers prohibited in production code
- **Rationale:** Makes static analysis difficult
- **Exception:** Test mocking frameworks may use function pointers
- **Check Method:** Code review, grep
- **Severity:** MANDATORY

```c
// ❌ PROHIBITED - Function pointer
typedef void (*callback_t)(int);
void register_callback(callback_t cb);

// ✅ CORRECT - Direct function call
void handle_event(int value) {
    // Handle event directly
    (void)value;
}
```

**R9.4 - No Multi-Level Pointers**
- **Rule:** Pointer-to-pointer prohibited
- **Rationale:** Complexity and error-prone
- **Exception:** C string arrays (`char* argv[]`)
- **Check Method:** Code review
- **Severity:** MANDATORY

```c
// ❌ PROHIBITED - Multi-level pointer
void modify_pointer(int** p) {
    *p = NULL;  // Multi-level complexity and confusion
}

int value = 10;
int* ptr = &value;
modify_pointer(&ptr);  // Hard to reason about

// ✅ CORRECT - Use return value
int* create_pointer(int* initial_value) {
    if (initial_value == NULL) {
        return NULL;
    }
    return initial_value;
}

int value = 10;
int* ptr = create_pointer(&value);  // Clear and simple

// ✅ ALSO CORRECT - Use struct wrapper
typedef struct {
    int* ptr;
} PointerHandle;

PointerHandle create_handle(int* initial_value) {
    PointerHandle handle;
    handle.ptr = initial_value;
    return handle;
}

int value = 10;
PointerHandle handle = create_handle(&value);  // Encapsulated
```

**R9.5 - No Opaque Ownership Transfers**
- **Rule:** Avoid ownership transfer patterns that obscure lifetime
- **Rationale:** Hidden ownership increases risk of leaks and use-after-free
- **Check Method:** Code review
- **Severity:** RECOMMENDED

---

## Rule 10: Aggressive Compiler Warnings and Static Analysis

**Principle:** Compile with all warnings enabled and use static analysis tools.

### Requirements

**R10.1 - Compiler Warning Flags**
- **Rule:** Must compile with `-Wall -Wextra -Werror -pedantic`
- **Rationale:** Compiler catches many common errors
- **Check Method:** Build system configuration
- **Severity:** CRITICAL

```cmake
# CMakeLists.txt - MANDATORY compiler flags
add_compile_options(
    -Wall          # Enable all warnings
    -Wextra        # Enable extra warnings
    -Werror        # Treat warnings as errors
    -pedantic      # Strict ISO C/C++ compliance
    -Wconversion   # Warn on implicit conversions
    -Wshadow       # Warn on variable shadowing
)
```

**R10.2 - Zero Warnings Policy**
- **Rule:** Code must compile with zero warnings
- **Rationale:** Warnings indicate potential bugs
- **Exception:** None - fix or suppress with justification
- **Check Method:** CI/CD pipeline
- **Severity:** CRITICAL

```c
// ❌ PROHIBITED - Unused variable warning
void process_value(int value) {
    int result = calculate(value);  // Assigned but never used
}

// ✅ CORRECT - Use the value or explicitly discard
void process_value(int value) {
    int result = calculate(value);
    apply_result(result);
}

// ✅ ALSO CORRECT - Explicitly discard if unused by design
void process_value(int value) {
    (void)value;  // Intentionally unused
}

// ❌ PROHIBITED - Uninitialized variable
void calculate() {
    int total;
    total = total + 5;  // Used before initialization
}

// ✅ CORRECT - Initialize all variables
void calculate() {
    int total = 0;
    total = total + 5;  // Safe
}

// ❌ PROHIBITED - Implicit narrowing conversion
void set_speed(float percent) {
    uint8_t pwm = percent * 255;  // Implicit double to int conversion
}

// ✅ CORRECT - Explicit cast documents intent
void set_speed(float percent) {
    uint8_t pwm = (uint8_t)(percent * 255);  // Explicit cast
}

// ❌ PROHIBITED - Shadowing
void outer() {
    int counter = 0;
    {
        int counter = 1;  // Shadows outer counter - confusing!
    }
}

// ✅ CORRECT - Use different names
void outer() {
    int total_counter = 0;
    {
        int loop_counter = 1;  // Clear and distinct name
    }
}
```

**R10.3 - Static Analysis**
- **Rule:** Run cppcheck on every commit
- **Rationale:** Catches errors beyond compiler capabilities
- **Check Method:** Automated in pipeline
- **Severity:** MANDATORY

```bash
# Required static analysis command
# Use --std=c++17 for C++ projects
cppcheck --enable=all \
         --error-exitcode=1 \
         --suppress=missingIncludeSystem \
         --std=c11 \
         src/
```

```c
// ❌ CAUGHT BY STATIC ANALYSIS - Memory leak
void load_config(void) {
    char* buffer = (char*)malloc(1024);
    if (buffer == NULL) {
        return;  // Leak! Allocated memory never freed
    }
    // ...
    process_buffer(buffer);
    // Returns without free()
}

// ✅ CORRECT - Proper resource cleanup
void load_config(void) {
    char* buffer = (char*)malloc(1024);
    if (buffer == NULL) {
        return ERR_NO_MEMORY;
    }
    
    ErrorCode result = process_buffer(buffer);
    free(buffer);  // Always cleanup
    return result;
}

// ❌ CAUGHT BY STATIC ANALYSIS - Dead code
int validate_range(int value) {
    if (value < 0) {
        return ERR_NEGATIVE;
    }
    return ERR_OK;
    printf("Validation complete\n");  // Unreachable code
}

// ✅ CORRECT - No code after return
int validate_range(int value) {
    if (value < 0) {
        return ERR_NEGATIVE;
    }
    // All reachable code before final return
    return ERR_OK;
}

// ❌ CAUGHT BY STATIC ANALYSIS - Unchecked function result
void read_sensor(void) {
    int value;
    HAL_read_adc(&value);  // Non-zero return means error!
    process_value(value);  // Processing with possibly invalid value
}

// ✅ CORRECT - Always check return values
void read_sensor(void) {
    int value;
    ErrorCode err = HAL_read_adc(&value);
    if (err != ERR_OK) {
        return err;  // Handle error
    }
    process_value(value);  // Safe to process
}
```

**R10.4 - Static Analysis Results**
- **Rule:** Zero errors, zero warnings from static analysis
- **Rationale:** Each issue is a potential defect
- **Exception:** False positives must be documented and suppressed inline
- **Check Method:** CI/CD pipeline
- **Severity:** MANDATORY

```c
// ✅ CORRECT - Inline suppression with justification
void example() {
    // cppcheck-suppress unusedVariable
    // Variable used in assertion, may appear unused in release build
    int debug_counter = get_counter();
    assert(debug_counter >= 0);
}
```

**R10.5 - MISRA C:2012 Compliance (Optional)**
- **Rule:** Strive for MISRA C:2012 compliance where practical
- **Rationale:** Industry standard for safety-critical C
- **Exception:** Some MISRA rules may not map cleanly to all C++ usage
- **Check Method:** MISRA checker tools
- **Severity:** RECOMMENDED

---

## Project-Specific Guidelines

### Naming Conventions

**R11.1 - Function Names**
- **Rule:** `Module_functionName()` - PascalCase module, camelCase function
- **Example:** `MotorController_set_direction()`, `HAL_read_button()`
- **Rationale:** Consistent with project codebase
- **Severity:** MANDATORY

```c
// ❌ PROHIBITED - Inconsistent naming
void setMotorPwm() { }           // No module prefix
void motor_controller_update() { } // Module not PascalCase
void MC_SetPWM() { }             // Function not camelCase

// ✅ CORRECT - Consistent naming
void MotorController_set_pwm() { }
void HAL_read_sensor() { }
void DeskApp_update_state() { }
```

**R11.2 - Variable Names**
- **Rule:** `snake_case` for local variables, `SCREAMING_SNAKE_CASE` for constants
- **Example:** `button_state`, `MAX_PWM_VALUE`
- **Severity:** MANDATORY

```c
// ❌ PROHIBITED - Inconsistent naming
int ButtonState;          // PascalCase for local variable
const int max_pwm = 255; // lowercase for constant

// ✅ CORRECT - Consistent naming
int button_state;           // snake_case for variables
const int MAX_PWM = 255;    // SCREAMING_SNAKE_CASE for constants
static int motor_pwm = 0;   // snake_case for static
```

**R11.3 - Type Names**
- **Rule:** `CamelCase` for classes/structs, `snake_case_t` for typedefs
- **Example:** `MotorController`, `error_code_t`
- **Severity:** MANDATORY

```c
// ❌ PROHIBITED - Inconsistent type naming
struct motor_controller { };  // Should be CamelCase
typedef int ErrorCode;        // Should have _t suffix

// ✅ CORRECT - Consistent type naming
struct MotorController {
    uint8_t pwm;
    MotorDirection direction;
};

typedef enum {
    ERR_OK = 0,
    ERR_INVALID_PARAM,
    ERR_TIMEOUT
} error_code_t;
```

### Safety-Critical Code

**R12.1 - Safety Markers**
- **Rule:** Mark safety-critical sections with `// SAFETY-CRITICAL` comment
- **Example:** See motor control, limit checking, error handling
- **Rationale:** Easy identification for review and analysis
- **Severity:** MANDATORY

**R12.2 - Fail-Safe Defaults**
- **Rule:** All safety states must default to safe condition
- **Example:** Motor stopped, power off, brakes engaged
- **Severity:** CRITICAL

```c
// ✅ CORRECT - Fail-safe initialization
typedef struct {
    MotorDirection direction;
    uint8_t pwm;
    bool enabled;
} MotorState;

static MotorState MotorState_init(void) {
    MotorState state;
    state.direction = DIR_STOP;  // Safe default
    state.pwm = 0;               // Safe default (off)
    state.enabled = false;       // Safe default (disabled)
    return state;
}
```

### Testing Requirements

**R13.1 - Unit Test Coverage**
- **Rule:** All functions must have unit tests
- **Target:** 100% statement coverage
- **Check Method:** Coverage tools (gcov/lcov)
- **Severity:** MANDATORY

**R13.2 - Test Naming**
- **Rule:** Tests named `TC_<Module>_<Requirement>_<Description>`
- **Example:** `TC_SWReq001_001_MotorStopsOnButtonRelease`
- **Severity:** MANDATORY

---

## Rule 14: Code Quality Metrics

**Principle:** Enforce measurable code quality thresholds to prevent complexity creep and technical debt.

### Requirements

**R14.1 - Limited Function Length**
- **Rule:** Functions must not exceed 60 lines of executable code (excluding comments/whitespace)
- **Threshold:** ⚠️ Yellow flag 40+ lines, 🔴 Red flag 60+ lines
- **Rationale:** 
  - Functions >60 lines often violate single responsibility principle
  - NASA Power of Ten baseline; proven for safety-critical systems
  - Fits on single screen → easier code review and testing
  - Correlates with cyclomatic complexity ~10
- **Check Method:** Automated line count analysis per function
- **Severity:** MANDATORY
- **Automation:** `rule_RULE-069_R14_1_function_length.py`

```c
// ❌ PROHIBITED - Function too long (>60 lines)
void process_sensor_data_complex(uint16_t* data, uint16_t size) {
    // Line 1: Validation
    if (data == NULL) return;
    if (size == 0) return;
    
    // Lines 5-25: Complex processing block
    for (int i = 0; i < size; i++) {
        if (data[i] > 1000) {
            // ... 15+ lines of nested logic ...
        }
    }
    
    // Lines 26-60: More processing
    for (int i = 0; i < size; i++) {
        if (data[i] < 100) {
            // ... 15+ lines more ...
        }
    }
    // Total: 60+ lines! This should be split.
}

// ✅ CORRECT - Refactored into smaller functions
void process_sensor_data(uint16_t* data, uint16_t size) {
    if (!validate_sensor_data(data, size)) {
        return;
    }
    
    filter_high_values(data, size);
    filter_low_values(data, size);
}

void filter_high_values(uint16_t* data, uint16_t size) {
    // Single responsibility: handle values > 1000
    for (int i = 0; i < size; i++) {
        if (data[i] > 1000) {
            data[i] = 1000;
        }
    }
}

void filter_low_values(uint16_t* data, uint16_t size) {
    // Single responsibility: handle values < 100
    for (int i = 0; i < size; i++) {
        if (data[i] < 100) {
            data[i] = 0;
        }
    }
}
```

**Benefits:**
- ✅ Forces single responsibility principle adherence
- ✅ Easier unit testing (fewer code paths to cover)
- ✅ Reduces bug density (proven linear correlation)
- ✅ Improves code review effectiveness
- ✅ Better maintainability (context stays in memory)

**Industry Precedent:** NASA JPL Power of Ten (Rule 4), Google C++ Style Guide, Linux kernel standards

---

**R14.2 - Limited Function Parameters**
- **Rule:** Functions must not exceed 4 parameters
- **Threshold:** ⚠️ Yellow at 4 params, 🔴 Red at 5+ params
- **Rationale:**
  - 4 parameters is cognitive limit for most developers
  - More parameters = harder to test and understand
  - Forces better data encapsulation
  - Improves API clarity
- **Check Method:** Parameter count analysis per function
- **Severity:** MANDATORY
- **Automation:** `rule_RULE-070_R14_2_parameter_count.py`

```c
// ❌ PROHIBITED - Too many parameters
void set_motor_config(uint8_t pwm, enum Direction dir, bool enabled, 
                      uint16_t timeout, int acceleration, float curve) {
    // 6 parameters! Unclear caller intent, hard to test
    // ...
}

// ✅ CORRECT - Encapsulate in struct
typedef struct {
    uint8_t pwm;
    enum Direction direction;
    bool enabled;
    uint16_t timeout;
    int acceleration;
    float curve;
} MotorConfig;

void set_motor_config(const MotorConfig* config) {
    // Single parameter! Clear intent, testable
    assert(config != NULL);
    // ...
}

// Caller side is CLEARER now:
MotorConfig cfg = {
    .pwm = 128,
    .direction = DIR_UP,
    .enabled = true,
    .timeout = 1000,
    .acceleration = 50,
    .curve = 1.5f
};
set_motor_config(&cfg);  // Much clearer than 6 args!
```

**Benefits:**
- ✅ Simpler unit test setup (fewer mock parameters)
- ✅ Clearer function contracts
- ✅ Easier to extend without breaking API
- ✅ Forces better data structure design

---

**R14.3 - Limited Nesting Depth**
- **Rule:** Block nesting must not exceed 4 levels
- **Threshold:** ⚠️ Yellow at 4 levels, 🔴 Red at 5+ levels
- **Rationale:**
  - Each nesting level increases cognitive load exponentially
  - Most developers reliably understand only 3-4 levels
  - Correlates strongly with error-prone code
  - Improves readability dramatically
- **Check Method:** Nesting depth analysis per function
- **Severity:** MANDATORY
- **Automation:** `rule_RULE-071_R14_3_nesting_depth.py`

```c
// ❌ PROHIBITED - 5+ levels of nesting
void process_depth_problem(uint8_t* data, uint16_t size) {
    if (data != NULL) {                       // Level 1
        for (int i = 0; i < size; i++) {    // Level 2
            if (data[i] > THRESHOLD) {      // Level 3
                while (data[i] < MAX) {     // Level 4
                    if (check_valid()) {    // Level 5 ❌ TOO DEEP!
                        process();
                    }
                }
            }
        }
    }
}

// ✅ CORRECT - Refactored for clarity (4 levels max)
void process_depth_correct(uint8_t* data, uint16_t size) {
    if (data == NULL) {
        return;  // Guard clause - early exit
    }
    
    for (int i = 0; i < size; i++) {        // Level 1
        if (data[i] > THRESHOLD) {          // Level 2
            process_high_value(&data[i]);   // Extracted function
        }
    }
}

// Helper function keeps nesting low
static void process_high_value(uint8_t* value) {
    if (value == NULL) return;
    
    while (*value < MAX) {                  // Level 1 (in this context)
        if (check_valid()) {                // Level 2
            process();
        }
    }
}

// Better yet: use guard clauses to eliminate nesting
static void process_high_value_simple(uint8_t* value) {
    if (value == NULL) return;
    if (*value >= MAX) return;
    if (!check_valid()) return;
    
    process();  // No nesting! Crystal clear.
}
```

**Benefits:**
- ✅ Dramatically improves code readability
- ✅ Reduces cognitive load on reviewers
- ✅ Decreases error probability
- ✅ Encourages extraction of helper functions

---

**R14.4 - Limited File Length**
- **Rule:** Source files must not exceed 800 lines of code
- **Threshold:** ⚠️ Yellow at 600 lines, 🔴 Red at 800+ lines
- **Rationale:**
  - Large files often contain multiple responsibilities
  - 800+ lines indicates need for module splitting
  - Mirrors function length rule but at module level
  - Improves compilation time and coupling
- **Check Method:** Line count analysis per file
- **Severity:** MANDATORY
- **Automation:** `rule_RULE-072_R14_4_file_length.py`

```c
// ❌ PROHIBITED - Motor controller file too long (800+ lines)
// file: motor_controller.cpp
// Contains: initialization, control, monitoring, diagnostics, testing
// Total: 950 lines - should be split

// ✅ CORRECT - Split by responsibility
// File 1: motor_controller.cpp (280 lines)
// - Core motor control API only
// - set_speed(), get_status(), stop()

// File 2: motor_diagnostics.cpp (320 lines)
// - Fault detection and reporting
// - check_current_limit(), get_temperature()

// File 3: motor_calibration.cpp (240 lines)
// - Startup calibration and safety checks
// - calibrate_min(), calibrate_max(), verify_safety()
```

**Benefits:**
- ✅ Enforces single responsibility at module level
- ✅ Easier to navigate large codebases
- ✅ Reduces recompilation impact
- ✅ Increases code reusability and modularity
- ✅ Improves test isolation

---

**R14.5 - Minimum Assertion Density**
- **Rule:** Functions must contain minimum 2 assertions on average
- **Threshold:** 🟡 Warning if < 2 assertions per function (average across module)
- **Rationale:**
  - Defensive programming requires invariant checking
  - Critical for ISO 25119 safety requirements
  - Catches assumptions that may be invalid
  - Low assertion density = low defensive rigor
- **Check Method:** Assertion count per function analysis
- **Severity:** MANDATORY (for safety functions), RECOMMENDED (general)
- **Automation:** `rule_RULE-073_R14_5_assertion_density.py`

```c
// ❌ PROHIBITED - Insufficient assertions (only 1 per 10-line function)
uint8_t calculate_duty_cycle_unsafe(uint16_t target_rpm) {
    assert(target_rpm <= MAX_RPM);  // Only 1 assertion!
    
    // What if MAX_RPM is 0? What if multiplication overflows?
    // What if final value >255?
    uint16_t scaled = (target_rpm * 255) / MAX_RPM;
    return (uint8_t)scaled;  // Could truncate or overflow!
}

// ✅ CORRECT - Comprehensive assertions document assumptions
uint8_t calculate_duty_cycle_safe(uint16_t target_rpm) {
    // Input validation
    assert(target_rpm <= MAX_RPM);
    assert(MAX_RPM > 0);
    
    // Calculation with sanity checks
    uint16_t scaled = (target_rpm * 255) / MAX_RPM;
    
    // Output validation
    assert(scaled <= 255);
    
    return (uint8_t)scaled;
}

// Safety-critical function example
bool is_desk_position_safe(int16_t position_mm) {
    // Preconditions
    assert(position_mm >= MIN_DESK_HEIGHT_MM);
    assert(position_mm <= MAX_DESK_HEIGHT_MM);
    assert(motor_initialized);
    
    // Check limit switches (independent verification)
    bool limit_safe = !limit_switch_pressed();
    assert(!limit_safe || limit_switch_pressed());  // Assumption check
    
    // Plausibility check
    bool position_plausible = (position_mm < MAX_LIMIT_POSITION);
    assert(position_plausible);
    
    // Postcondition
    assert(limit_safe == !limit_switch_pressed());
    
    return limit_safe && position_plausible;
}
```

**Assertion Best Practices:**
- ✅ Place assertions at function entry (preconditions)
- ✅ Place assertions before critical operations (invariants)
- ✅ Place assertions at function exit (postconditions)
- ✅ Use `assert()` for invariants that MUST be true
- ✅ Use runtime `if` checks for potentially invalid user input
- ✅ Document why each assertion matters

**Benefits:**
- ✅ Documents implicit assumptions explicitly
- ✅ Catches edge cases during testing and in field
- ✅ Improves debugging (assertion identifies exact failure)
- ✅ Critical for ISO 25119 compliance
- ✅ Aligns with NASA R5 (defensive assertions)

**Formula:** Ideal Density = 2-3 assertions per function

Example:
```
10-line function → 2+ assertions ideal
30-line function → 5-7 assertions ideal  
60-line function → 8-10 assertions (but should be shorter!)
```

---

## MISRA C:2012 Compliance Rules

### Overview

MISRA C:2012 "Guidelines for the use of the C language in critical systems" defines 143 rules across 22 categories. This section covers the most critical rules for embedded safety applications, extracted from MISRA C:2012.

**Rule Categories:** Required (SHALL), Mandatory (SHALL), Advisory (SHOULD)

### Core MISRA C Rules for Safety-Critical Systems

**MISRA C Rule 1.3: No Undefined or Critical Unspecified Behaviour (Required)**
- **Category:** Required (SHALL)
- **Rule:** There shall be no occurrence of undefined or critical unspecified behaviour
- **Rationale:** Undefined behavior makes programs non-portable and unpredictable
- **Standard Refs:** C90 Undefined behaviors, C99 Undefined behaviors
- **Check:** Static analysis (cppcheck), compiler warnings
- **Severity:** CRITICAL
- **Automation:** `cppcheck --enable=all`, GCC `-Wundef`

```c
// ❌ PROHIBITED - Undefined behavior
int overflow = INT_MAX + 1;  // Signed overflow - undefined!
int shift = 1 << 32;  // Shift >= width - undefined!

// ✅ CORRECT - Well-defined behavior
if (value < INT_MAX) {
    value++;
}
```

**MISRA C Rule 2.1: No Unreachable Code (Required)**
- **Category:** Required (SHALL)
- **Rule:** A project shall not contain unreachable code
- **Rationale:** Unreachable code indicates logic errors and wastes resources
- **Standards:** IEC 61508-7 C.5.9, DO-178C 6.4.4.3.c
- **Check:** Static analysis, coverage analysis
- **Severity:** MANDATORY
- **Automation:** `cppcheck --enable=unusedFunction`, gcov

```c
// ❌ PROHIBITED - Unreachable code
void bad_function() {
    return;
    int x = 5;  // Unreachable!
}

// ✅ CORRECT - All code reachable
void good_function() {
    int x = 5;
    return;
}
```

**MISRA C Rule 2.2: No Dead Code (Required)**
- **Category:** Required (SHALL)
- **Rule:** There shall be no dead code
- **Rationale:** Operations with no effect indicate errors
- **Standards:** IEC 61508-7 C.5.10, ISO 26262-6 9.4.5, DO-178C 6.4.4.3.c
- **Check:** Static analysis, code review
- **Severity:** MANDATORY
- **Automation:** `cppcheck --enable=style`

```c
// ❌ PROHIBITED - Dead code
void dead_assignment() {
    int x = 5;
    x = 10;  // Dead - never used
}

// ✅ CORRECT - All code has effect
void live_code() {
    int x = 5;
    use_value(x);
}
```

**MISRA C Rule 8.1: Types Shall Be Explicitly Specified (Required)**
- **Category:** Required (SHALL)
- **Rule:** Types shall be explicitly specified (no implicit int)
- **Rationale:** Prevents confusion from C90 implicit int assumption
- **Check:** Compiler warnings
- **Severity:** MANDATORY
- **Automation:** GCC `-Wimplicit-int`

```c
// ❌ PROHIBITED - Implicit type (C90)
extern func();  // Assumes int return type

// ✅ CORRECT - Explicit type
extern int func(void);
```

**MISRA C Rule 8.3: Consistent Function Declarations (Required)**
- **Category:** Required (SHALL)
- **Rule:** All declarations of an object or function shall use the same names and type qualifiers
- **Rationale:** Encourages strong typing and interface consistency
- **Check:** Static analysis
- **Severity:** MANDATORY
- **Automation:** `cppcheck --enable=all`

```c
// ❌ PROHIBITED - Inconsistent declarations
extern void func(signed int);
void func(int x) { }

// ✅ CORRECT - Consistent
extern void func(int x);
void func(int x) { }
```

**MISRA C Rule 9.1: Automatic Variables Must Be Initialized Before Read (Mandatory)**
- **Category:** Mandatory (SHALL)
- **Rule:** The value of an object with automatic storage duration shall not be read before it has been set
- **Rationale:** Reading uninitialized variables is undefined behavior
- **Check:** Static analysis
- **Severity:** CRITICAL
- **Automation:** GCC `-Wuninitialized`, `cppcheck --enable=all`

```c
// ❌ PROHIBITED - Uninitialized read
void bad_init(void) {
    int x;
    if (x > 0) { }
}

// ✅ CORRECT - Initialize before use
void good_init(void) {
    int x = 0;
    if (x > 0) { }
}
```

**MISRA C Rule 10.1: Operands Must Have Appropriate Essential Types (Required)**
- **Category:** Required (SHALL)
- **Rule:** Operands shall not be of an inappropriate essential type
- **Rationale:** Prevents unintended implicit promotions and conversions
- **Check:** Static analysis, compiler warnings
- **Severity:** MANDATORY
- **Automation:** GCC `-Wconversion`, `cppcheck --enable=all`

```c
// ❌ PROHIBITED - Mixed essential types
uint8_t u8 = 10U;
int16_t s16 = -1;
int result = u8 + s16;  // Mixed signed/unsigned

// ✅ CORRECT - Explicit, validated conversion
int16_t s16_safe = s16;
int result = (int)u8 + (int)s16_safe;
```

**MISRA C Rule 10.3: No Narrowing or Cross-Category Assignments (Required)**
- **Category:** Required (SHALL)
- **Rule:** The value of an expression shall not be assigned to an object with a narrower essential type or of a different essential type category
- **Rationale:** Prevents data loss and type confusion
- **Check:** Compiler warnings
- **Severity:** MANDATORY
- **Automation:** GCC `-Wconversion`, `-Wsign-conversion`

```c
// ❌ PROHIBITED - Narrowing without cast
uint8_t val8 = 300U;

// ✅ CORRECT - Explicit cast with validation
int raw = 300;
if (raw <= 255) {
    uint8_t val8 = (uint8_t)raw;
}
```

**MISRA C Rule 10.4: Operands Must Share Essential Type Category (Required)**
- **Category:** Required (SHALL)
- **Rule:** Both operands of an operator subject to the usual arithmetic conversions shall have the same essential type category
- **Rationale:** Prevents unintended conversions and loss of information
- **Check:** Static analysis
- **Severity:** MANDATORY
- **Automation:** `cppcheck --enable=all`

```c
// ❌ PROHIBITED - Mixed essential categories (implicit promotion)
uint16_t u16 = 100U;
int16_t s16 = -2;
int32_t sum = u16 + s16;  // Implicit conversion - ambiguous!

// ❌ ALSO PROHIBITED - Comparison with mixed types
uint8_t byte = 255U;
int16_t value = -1;
if (byte > value) { }  // Are we comparing unsigned or signed?

// ✅ CORRECT - Explicit conversion to common type
uint16_t u16 = 100U;
int16_t s16 = -2;
int32_t sum = (int32_t)u16 + (int32_t)s16;  // Explicit and clear

// ✅ CORRECT - Ensure both operands are same category
int8_t signed_val = -1;
int8_t unsigned_val = 255;
int16_t result = (int16_t)signed_val + (int16_t)unsigned_val;  // Cast both to same type
```

**MISRA C Rule 11.3: No Casting Between Different Object Pointer Types (Required)**
- **Category:** Required (SHALL)
- **Rule:** A cast shall not be performed between a pointer to object type and a pointer to a different object type
- **Rationale:** May cause alignment errors and undefined behavior
- **Check:** Static analysis
- **Severity:** CRITICAL
- **Automation:** `cppcheck --enable=all`

```c
// ❌ PROHIBITED - Pointer type punning
uint16_t* p16 = (uint16_t*)&value32;

// ✅ CORRECT - Use memcpy or unions only with approved deviation
uint16_t out;
memcpy(&out, &value32, sizeof(out));
```

**MISRA C Rule 12.1: Explicit Operator Precedence (Advisory)**
- **Category:** Advisory (SHOULD)
- **Rule:** The precedence of operators within expressions should be made explicit
- **Rationale:** Reduces misunderstanding and bugs
- **Check:** Code review
- **Severity:** RECOMMENDED
- **Automation:** Manual review

```c
// ⚠️ DISCOURAGED - Implicit precedence
if (a & b == c) { }

// ✅ CORRECT - Explicit parentheses
if ((a & b) == c) { }
```

**MISRA C Rule 13.2: Expression Side Effects Used Only Once (Required)**
- **Category:** Required (SHALL)
- **Rule:** The value of an expression and its persistent side effects shall be the same under all permitted evaluation orders
- **Rationale:** Order of evaluation is often unspecified
- **Check:** Static analysis
- **Severity:** CRITICAL
- **Automation:** `cppcheck --enable=style`

```c
// ❌ PROHIBITED - Multiple side effects
array[i++] = i++;

// ✅ CORRECT - Single side effect
array[i] = value;
i++;
```

**MISRA C Rule 14.3: Controlling Expressions Shall Not Be Invariant (Required)**
- **Category:** Required (SHALL)
- **Rule:** Controlling expressions shall not be invariant
- **Rationale:** Invariant conditions often indicate errors
- **Check:** Static analysis
- **Severity:** MANDATORY
- **Automation:** `cppcheck --enable=style`

```c
// ❌ PROHIBITED - Invariant condition
if (1) {
    do_something();
}

// ✅ CORRECT - Meaningful condition
if (sensor_value > THRESHOLD) {
    do_something();
}
```

**MISRA C Rule 16.3: Every Switch Clause Shall Have Unconditional Break (Required)**
- **Category:** Required (SHALL)
- **Rule:** An unconditional break statement shall terminate every switch-clause
- **Rationale:** Prevents accidental switch fallthrough bugs
- **Check:** Compiler warnings
- **Severity:** MANDATORY
- **Automation:** GCC `-Wimplicit-fallthrough`

```c
// ❌ PROHIBITED - No break
switch (state) {
    case STATE_INIT:
        init();
    case STATE_RUN:
        run();
        break;
}

// ✅ CORRECT - explicit break
switch (state) {
    case STATE_INIT:
        init();
        break;
    case STATE_RUN:
        run();
        break;
    default:
        break;
}
```

**MISRA C Rule 17.7: Return Value Shall Be Used (Required)**
- **Category:** Required (SHALL)
- **Rule:** The value returned by a function having non-void return type shall be used
- **Rationale:** Ignoring return values hides errors
- **Check:** Compiler warnings
- **Severity:** CRITICAL
- **Automation:** GCC `-Wunused-result`

```c
// ❌ PROHIBITED - Ignored return value
read_sensor();

// ✅ CORRECT - Check return value
int status = read_sensor();
if (status != OK) {
    handle_error(status);
}
```

**MISRA C Rule 18.1: Pointer Arithmetic Within Array Bounds (Required)**
- **Category:** Required (SHALL)
- **Rule:** A pointer resulting from arithmetic on a pointer operand shall address an element of the same array as that pointer operand
- **Rationale:** Out-of-bounds pointer arithmetic is undefined
- **Check:** Static analysis
- **Severity:** CRITICAL
- **Automation:** `cppcheck --enable=all`

```c
// ❌ PROHIBITED - Out of bounds arithmetic
int array[10];
int* p = &array[0];
p += 15;

// ✅ CORRECT - Bounded arithmetic
int* p = &array[0];
if (index < 10) {
    p += index;
}
```

**MISRA C Rule 21.3: No Dynamic Memory Allocation (Required)**
- **Category:** Required (SHALL)
- **Rule:** The memory allocation and deallocation functions of <stdlib.h> shall not be used
- **Rationale:** Dynamic allocation risks fragmentation and undefined behavior
- **Check:** Grep search
- **Severity:** CRITICAL
- **Automation:** `grep -r '\bmalloc\|calloc\|realloc\|free\b' src/`

```c
// ❌ PROHIBITED - Dynamic allocation
int* ptr = (int*)malloc(100U * sizeof(int));
free(ptr);

// ✅ CORRECT - Static or stack allocation
int array[100];
static int global_array[100];
```

**MISRA C Rule 21.6: No Standard I/O Functions (Required)**
- **Category:** Required (SHALL)
- **Rule:** The Standard Library input/output functions shall not be used
- **Rationale:** Standard I/O may be unavailable or non-deterministic on embedded targets
- **Check:** Grep search
- **Severity:** MANDATORY
- **Automation:** `grep -r '\bprintf\|scanf\|fopen\|fclose\b' src/`

```c
// ❌ PROHIBITED - Standard I/O
printf("Debug: %d\n", value);

// ✅ CORRECT - Target-specific logging
debug_log(value);
```

### MISRA Rule Categories

| Category | Rules | Automation Level | Tool |
|---|---|---|---|
| **Required** | Must comply | High | cppcheck, compiler |
| **Advisory** | Should comply | Medium | Code review, cppcheck |
| **Document** | Deviations must be documented | Manual | Review process |

---

## ISO 25119 Coding Requirements

### ISO 25119-3 Software Design Rules

ISO 25119-3:2018 specifies software design requirements for safety functions in agricultural machinery. Key coding requirements:

**ISO-001: Traceable Requirements**
- **Rule:** All code must trace to a software requirement
- **Rationale:** ISO 25119 mandates full traceability
- **Check:** Traceability matrix validation
- **Severity:** MANDATORY
- **Automation:** grep for requirement IDs in comments, traceability script

```c
// ✅ CORRECT - Requirement traceability
// Implements: SWReq-001 - Motor shall stop when button released
void check_button_release() {
    if (!button_pressed && motor_running) {
        stop_motor();  // SWReq-001
    }
}
```

**ISO-002: Defensive Programming Mandatory**
- **Rule:** Validate all inputs, check all outputs, assert invariants
- **Rationale:** ISO 25119 requires defensive programming techniques
- **Check:** Code review, assertion count
- **Severity:** MANDATORY
- **Automation:** Count assertions per function

**ISO-003: Software Diversity for Safety Functions**
- **Rule:** Critical safety decisions must use independent checks
- **Rationale:** Single point of failure prevention
- **Check:** Architecture review
- **Severity:** CRITICAL (for AgPL c or d)
- **Automation:** Manual architectural review

```c
// ✅ CORRECT - Dual-channel safety check
bool is_safe_to_move_up() {
    // Primary check: limit sensor
    bool primary_safe = !limit_switch_top;
    
    // Secondary check: position estimation
    bool secondary_safe = (estimated_position < MAX_POSITION);
    
    // Both must agree
    return primary_safe && secondary_safe;
}
```

**ISO-004: Fail-Safe Behavior**
- **Rule:** All error conditions must result in safe state
- **Rationale:** ISO 25119 core principle
- **Check:** Error handling review
- **Severity:** CRITICAL
- **Automation:** grep for error returns, verify safe state calls

**ISO-005: Watchdog Monitoring**
- **Rule:** Software must implement watchdog/alive monitoring
- **Rationale:** Detect CPU crashes and lockups
- **Check:** Architecture review
- **Severity:** MANDATORY (for AgPL c or d)
- **Automation:** Verify watchdog refresh calls

**ISO-006: Memory Integrity Checks**
- **Rule:** Critical data must use integrity checks (CRC, parity)
- **Rationale:** Detect RAM corruption
- **Check:** Code review
- **Severity:** MANDATORY (for AgPL c or d)
- **Automation:** Verify CRC calculation for critical data

**ISO-007: Plausibility Checks**
- **Rule:** Sensor values must be plausibility checked
- **Rationale:** Detect sensor failures
- **Check:** Code review
- **Severity:** MANDATORY
- **Automation:** Verify range checks on all sensor inputs

```c
// ❌ PROHIBITED - No plausibility checks
int16_t read_motor_current_unchecked() {
    return HAL_read_motor_current_ma();  // Assumes sensor is good
}

// ✅ CORRECT - Comprehensive plausibility checking
int16_t read_motor_current_checked(void) {
    int16_t current_ma = HAL_read_motor_current_ma();
    
    // Plausibility: motor current has physical limits
    const int16_t MAX_PLAUSIBLE_CURRENT = 5000;  // 5A max for this motor
    if (current_ma > MAX_PLAUSIBLE_CURRENT) {
        // Sensor failure or short circuit detected!
        trigger_safety_shutdown();
        return -1;  // Invalid reading
    }
    
    // Plausibility: negative current impossible (unidirectional)
    if (current_ma < 0) {
        // Sensor inversion or failure
        trigger_safety_shutdown();
        return -1;  // Invalid reading
    }
    
    // Plausibility: rate of change check
    static int16_t last_current = 0;
    const int16_t MAX_RATE_CHANGE = 500;  // Max 500mA/sample change
    if (abs(current_ma - last_current) > MAX_RATE_CHANGE) {
        // Unrealistic jump indicates sensor glitch
        return last_current;  // Return last known good value
    }
    
    last_current = current_ma;
    return current_ma;
}
```

### Defensive Programming (ISO 25119)

**ISO-008: Range Checking**
- **Rule:** All numeric parameters must be range-checked
- **Check:** Parameter validation at function entry
- **Severity:** MANDATORY
- **Automation:** Check for validation code in all public functions

```c
// ❌ PROHIBITED - No range checking
void set_motor_speed(uint8_t speed_percent) {
    motor_pwm = (speed_percent * 255) / 100;  // Assumes 0-100
}

// ✅ CORRECT - Comprehensive range checking
ErrorCode set_motor_speed(uint8_t speed_percent) {
    // Validate input range
    if (speed_percent > 100) {
        return ERR_OUT_OF_RANGE;
    }
    
    // Ensure motor is in safe state
    if (!motor_initialized) {
        return ERR_NOT_INITIALIZED;
    }
    
    // Convert and apply
    motor_pwm = (speed_percent * 255) / 100;
    return ERR_OK;
}

// ✅ ALSO GOOD - With assertions for documentation
void set_position_absolute(int16_t position_mm) {
    // Precondition: position must be within valid range for desk
    assert(position_mm >= MIN_DESK_HEIGHT_MM && 
           position_mm <= MAX_DESK_HEIGHT_MM);
    
    assert(motor_initialized);  // Safety check
    
    // Perform movement
    move_to_position(position_mm);
}
```

**ISO-009: State Machine Validity**
- **Rule:** State machines must validate state transitions
- **Check:** State transition matrix verification
- **Severity:** MANDATORY
- **Automation:** Verify default case in state switches

```c
// ❌ PROHIBITED - No transition validation
void change_state_unsafe(State new_state) {
    current_state = new_state;  // Any transition allowed!
}

// ❌ ALSO PROHIBITED - Default case missing
void handle_state(State s) {
    switch(s) {
        case STATE_IDLE:
            idle_handler();
            break;
        case STATE_MOVING:
            moving_handler();
            break;
        // What about unexpected states? No default!
    }
}

// ✅ CORRECT - Valid state transition checking
ErrorCode change_state(State new_state) {
    // Validate new state is in valid range
    if (new_state < STATE_MIN || new_state > STATE_MAX) {
        return ERR_INVALID_STATE;
    }
    
    // Check transition is legal per state machine diagram
    if (!is_valid_transition(current_state, new_state)) {
        return ERR_ILLEGAL_TRANSITION;
    }
    
    current_state = new_state;
    return ERR_OK;
}

// ✅ CORRECT - Default case always present
void handle_state(State s) {
    switch(s) {
        case STATE_IDLE:
            idle_handler();
            break;
        case STATE_MOVING:
            moving_handler();
            break;
        case STATE_ERROR:
            error_handler();
            break;
        default:
            // Unexpected state - safety shutdown!
            SAFETY_ASSERT(false);  // This should never happen
            trigger_fault();
            break;
    }
}
```

**ISO-010: Overflow Prevention**
- **Rule:** Arithmetic operations must check for overflow
- **Check:** Static analysis, runtime checks
- **Severity:** MANDATORY
- **Automation:** Compiler warnings, static analysis

```c
// ❌ PROHIBITED - No overflow detection
void accumulate_unsafe(uint16_t new_value) {
    total_sum += new_value;  // Could overflow without detection!
}

// ❌ ALSO PROHIBITED - Silent wrap-around
uint8_t counter = 255;
counter++;  // Now 0 - silent overflow!

// ✅ CORRECT - Overflow with saturating arithmetic
ErrorCode accumulate_safe(uint16_t new_value) {
    // Check if addition would overflow
    if (total_sum > (UINT16_MAX - new_value)) {
        total_sum = UINT16_MAX;  // Saturate at maximum
        return ERR_OVERFLOW;  // Notify caller
    }
    
    total_sum += new_value;
    return ERR_OK;
}

// ✅ CORRECT - Overflow detection with wider type
uint16_t safe_add_u16(uint16_t a, uint16_t b, bool* overflow) {
    // Use wider type to detect overflow
    uint32_t result = (uint32_t)a + (uint32_t)b;
    
    if (result > UINT16_MAX) {
        *overflow = true;
        return UINT16_MAX;  // Saturate
    }
    
    *overflow = false;
    return (uint16_t)result;
}

// ✅ ALSO CORRECT - Check before operation
uint8_t safe_increment(uint8_t value) {
    if (value == UINT8_MAX) {
        return UINT8_MAX;  // Already at max
    }
    return value + 1;  // Safe to increment
}
```

---

## Automated Checking

### Comprehensive Automated Checks Table

This table provides complete automation guidance for all rules. Use this for implementing automated checking scripts.

**Rule Scripts:** Each automated rule listed in the Rule Index has a dedicated script under `toolchain/rules/`.
Run a rule script by passing the source path:

```bash
python toolchain/rules/rule_RULE-001_R1_1_no_goto.py src/
```

All rule scripts use the shared helper library `toolchain/rules/common.py` to iterate and scan the provided path.

| Rule ID | Standard | Check Method | Tool/Command | Exit on Fail | Severity |
|---|---|---|---|---|---|
| **NASA Rules** |
| R1.1 | NASA-01 | Grep pattern | `grep -r '\bgoto\b' src/` | Yes | CRITICAL |
| R1.2 | NASA-01 | Grep pattern | `grep -r 'setjmp\|longjmp' src/` | Yes | CRITICAL |
| R1.3 | NASA-01 | Call graph analysis | Manual review | Yes | CRITICAL |
| R2.1 | NASA-02 | Loop bound analysis | Manual review | Yes | CRITICAL |
| R2.3 | NASA-02 | Grep pattern | `grep -r 'while\s*\(\s*true\s*\)' src/` | Review | CRITICAL |
| R3.1 | NASA-03 | Grep pattern | `grep -r '\bmalloc\|calloc\|realloc\|free\b' src/` | Yes | CRITICAL |
| R3.2 | NASA-03 | Hidden allocation review | Code review | Review | MANDATORY |
| R3.4 | NASA-03 | Stack usage analysis | Static analysis | Yes | MANDATORY |
| R4.1 | NASA-04 | Line count per function | `wc -l` or custom script | Yes | MANDATORY |
| R4.3 | NASA-04 | Cyclomatic complexity | `cppcheck --enable=all` | Yes | MANDATORY |
| R5.2 | NASA-05 | Parameter validation | Code review | No | MANDATORY |
| R5.3 | NASA-05 | Invariant assertions | Code review | No | CRITICAL |
| R6.4 | NASA-06 | Uninitialized variables | `gcc -Wuninitialized` | Yes | MANDATORY |
| R7.1 | NASA-07 | Unused result | `gcc -Wunused-result` | Yes | CRITICAL |
| R7.3 | NASA-07 | NULL dereference | `cppcheck --enable=all` | Yes | CRITICAL |
| R8.2 | NASA-08 | Function-like macros | `grep -r '#define.*(' src/` | Review | MANDATORY |
| R9.2 | NASA-09 | Pointer arithmetic | `cppcheck --enable=portability` | Review | MANDATORY |
| R9.3 | NASA-09 | Function pointers | `grep -r '\(\*.*\)\s*\(' src/` | Review | MANDATORY |
| R10.1 | NASA-10 | Compiler flags | Check CMakeLists.txt | Yes | CRITICAL |
| R10.2 | NASA-10 | Warning count | GCC/Clang output | Yes | CRITICAL |
| R10.3 | NASA-10 | Static analysis run | `cppcheck --enable=all src/` | Yes | MANDATORY |
| R10.4 | NASA-10 | Analysis error count | cppcheck XML output | Yes | MANDATORY |
| **MISRA C Rules** |
| MISRA-1.3 | MISRA C | Undefined/unspecified behavior | `cppcheck --enable=all` | Yes | CRITICAL |
| MISRA-2.1 | MISRA C | Unreachable code | `cppcheck --enable=unusedFunction` | Yes | MANDATORY |
| MISRA-2.2 | MISRA C | Dead code | `cppcheck --enable=style` | Yes | MANDATORY |
| MISRA-9.1 | MISRA C | Uninitialized auto vars | `gcc -Wuninitialized` | Yes | CRITICAL |
| MISRA-10.1 | MISRA C | Essential type misuse | `gcc -Wconversion` | Yes | MANDATORY |
| MISRA-10.3 | MISRA C | Narrowing assignment | `gcc -Wconversion` | Yes | MANDATORY |
| MISRA-11.3 | MISRA C | Pointer cast mismatch | `cppcheck --enable=all` | Yes | CRITICAL |
| MISRA-13.2 | MISRA C | Multiple side effects | `cppcheck --enable=style` | Review | CRITICAL |
| MISRA-16.3 | MISRA C | Switch fallthrough | `gcc -Wimplicit-fallthrough` | Yes | MANDATORY |
| MISRA-17.7 | MISRA C | Unused return value | `gcc -Wunused-result` | Yes | CRITICAL |
| MISRA-18.1 | MISRA C | Pointer arithmetic bounds | `cppcheck --enable=all` | Review | CRITICAL |
| MISRA-21.3 | MISRA C | Dynamic allocation | `grep -r '\bmalloc\|calloc\|realloc\|free\b' src/` | Yes | CRITICAL |
| MISRA-21.6 | MISRA C | Standard I/O usage | `grep -r '\bprintf\|scanf\|fopen\|fclose\b' src/` | Yes | MANDATORY |
| **ISO 25119 Requirements** |
| ISO-001 | ISO 25119 | Requirement trace | `grep -r 'SWReq-' src/` + validation | Review | MANDATORY |
| ISO-002 | ISO 25119 | Defensive prog | Assertion count script | Review | MANDATORY |
| ISO-004 | ISO 25119 | Fail-safe behavior | Error handling review | No | CRITICAL |
| ISO-007 | ISO 25119 | Plausibility checks | Range check validation | Review | MANDATORY |
| ISO-008 | ISO 25119 | Range checking | Parameter validation grep | Review | MANDATORY |
| ISO-009 | ISO 25119 | State validation | Default case in switches | Review | MANDATORY |
| ISO-010 | ISO 25119 | Overflow checks | Arithmetic analysis | Review | MANDATORY |
| R4.1 | Line count per function | Custom script | Yes |
| R4.3 | Cyclomatic complexity | cppcheck | Yes (if >10) |
| R7.1 | Unused result warnings | GCC `-Wunused-result` | Yes |
| R7.3 | NULL dereference | cppcheck | Yes |
| R9.2 | Pointer arithmetic detection | cppcheck | Review |
| R9.3 | grep function pointers | grep | Review |
| R10.1 | Compiler flags present | CMake check | Yes |
| R10.2 | Compilation warnings | GCC/Clang | Yes |
| R10.3 | cppcheck execution | cppcheck | Yes |

### Automation Scripts Reference

These commands can be integrated into automated checking scripts:

**Basic Prohibition Checks:**
```bash
#!/bin/bash
# Check for prohibited constructs

ERRORS=0

# NASA-01: No goto
if grep -rn '\bgoto\b' src/; then
    echo "ERROR: goto statement found"
    ERRORS=$((ERRORS+1))
fi

# NASA-03: No dynamic allocation
if grep -rn '\bmalloc\|calloc\|realloc\|free\b' src/; then
    echo "ERROR: Dynamic memory allocation found"
    ERRORS=$((ERRORS+1))
fi

exit $ERRORS
```

**Function Length Check:**
```python
#!/usr/bin/env python3
# Check function length (NASA-04)

import re
import sys
from pathlib import Path

MAX_FUNCTION_LINES = 60
errors = 0

for src_file in list(Path('src').rglob('*.c')) + list(Path('src').rglob('*.cpp')):
    with open(src_file) as f:
        content = f.read()
    
    # Simple function detection for C/C++ (improve as needed)
    functions = re.findall(
        r'^[a-zA-Z_][\w\s\*]*\s+[a-zA-Z_][\w]*\s*\([^;]*\)\s*\{([^}]*)\}',
        content,
        re.MULTILINE | re.DOTALL
    )
    
    for func_body in functions:
        lines = [l for l in func_body.split('\n') 
                if l.strip() and not l.strip().startswith('//')]
        if len(lines) > MAX_FUNCTION_LINES:
            print(f"ERROR: Function in {src_file} exceeds {MAX_FUNCTION_LINES} lines")
            errors += 1

sys.exit(1 if errors > 0 else 0)
```

**Assertion Density Check:**
```python
#!/usr/bin/env python3
# Check assertion density (NASA-05, ISO-002)

import re
import sys
from pathlib import Path

MIN_ASSERTIONS_PER_FUNCTION = 2
warnings = 0

for src_file in list(Path('src').rglob('*.c')) + list(Path('src').rglob('*.cpp')):
    with open(src_file) as f:
        content = f.read()
    
    # Count functions (C/C++)
    functions = re.findall(r'^[a-zA-Z_][\w\s\*]*\s+[a-zA-Z_][\w]*\s*\([^;]*\)', content, re.MULTILINE)
    
    # Count assertions
    assertions = len(re.findall(r'\bassert\(', content))
    
    if len(functions) > 0:
        density = assertions / len(functions)
        if density < MIN_ASSERTIONS_PER_FUNCTION:
            print(f"WARNING: {src_file} has low assertion density: {density:.1f}")
            warnings += 1

print(f"Assertion density check: {warnings} warnings")
sys.exit(0)  # Warning only, don't fail build
```

**Requirement Traceability Check:**
```python
#!/usr/bin/env python3
# Check requirement traceability (ISO-001)

import re
import sys
from pathlib import Path

requirements = []  # Load from requirements document
traced_requirements = set()

for src_file in list(Path('src').rglob('*.c')) + list(Path('src').rglob('*.cpp')):
    with open(src_file) as f:
        content = f.read()
    
    # Find requirement IDs in comments
    req_ids = re.findall(r'SWReq-\d+', content)
    traced_requirements.update(req_ids)

print(f"Traced {len(traced_requirements)} requirements in code")
# Compare with requirement database for gaps
```

### Manual Review Rules (Require human judgment)

| Rule ID | Standard | Description | Review Focus |
|---|---|---|---|
| R1.3 | NASA-01 | Recursion prohibited | Function call graph analysis |
| R1.4 | NASA-01 | Single entry/exit preferred | Code review for clarity |
| R2.1 | NASA-02 | Loop bounds provable | Loop termination analysis |
| R2.4 | NASA-02 | Loop invariants documented | Documentation review |
| R4.2 | NASA-04 | Single responsibility | Design review |
| R5.1 | NASA-05 | Assertion density (2+/function) | Count assertions per function |
| R5.2 | NASA-05 | Precondition checks present | Parameter validation review |
| R6.1 | NASA-06 | Variable scope minimized | Code structure review |
| R6.2 | NASA-06 | Global variable justification | Architecture review |
| MISRA-13.2 | MISRA C | Side effects in expressions | Expression complexity |
| ISO-003 | ISO 25119 | Software diversity | Architectural analysis |
| ISO-005 | ISO 25119 | Watchdog implementation | Verify refresh calls |
| ISO-006 | ISO 25119 | Memory integrity checks | CRC implementation review |
| ISO-009 | ISO 25119 | State transition validation | State machine analysis |

---

## Appendix: Quick Reference

### Critical Rules (Must Never Violate)

1. ❌ **NO goto** (R1.1)
2. ❌ **NO setjmp/longjmp** (R1.2)
3. ❌ **NO recursion** (R1.3)
4. ❌ **NO unbounded loops** (R2.1, R2.3)
5. ❌ **NO malloc/free** (R3.1)
6. ❌ **NO hidden dynamic allocation** (R3.2)
7. ✅ **CHECK all return values** (R7.1)
8. ✅ **VALIDATE all pointers** (R7.3)
9. ✅ **COMPILE with -Wall -Wextra -Werror** (R10.1)
10. ✅ **ZERO warnings, ZERO static analysis errors** (R10.2, R10.4)

### Recommended Practices

- ✅ Keep functions under 60 lines (R4.1)
- ✅ Use 2+ assertions per function (R5.1)
- ✅ Minimize variable scope (R6.1)
- ✅ Prefer non-NULL interfaces where available (R9.1)
- ✅ Initialize variables at declaration (R6.4)
- ✅ Document safety-critical code (R12.1)
- ✅ Write unit tests for all functions (R13.1)

### Automated Checking Command

```bash
# Run from workspace root
python toolchain/run-pipeline.py all

# Includes:
# - Build with all warnings
# - Static analysis (cppcheck)
# - Unit/component/integration tests
# - Dual motor type validation
```

### Tool Configuration

**Compiler Flags (GCC/Clang) - Full Set:**
```bash
# Mandatory flags for compliance
-Wall                    # All warnings
-Wextra                  # Extra warnings
-Werror                  # Treat warnings as errors
-pedantic                # Strict ISO C/C++ compliance
-std=c11                 # C standard (use -std=c++17 for C++)
-Wconversion             # Implicit conversions (MISRA-003)
-Wshadow                 # Variable shadowing
-Wunused-result          # Unchecked return values (R7.1)
-Wimplicit-fallthrough   # Switch fallthrough (MISRA-005)
-Wfloat-equal            # Floating point comparison
-Wundef                  # Undefined macros
-Wcast-align             # Alignment cast issues
```

**Cppcheck Configuration - Comprehensive:**
```bash
# Run cppcheck with full analysis
# Use --std=c++17 for C++ projects
cppcheck \
    --enable=all \
    --std=c11 \
    --inconclusive \
    --force \
    --verbose \
    --error-exitcode=1 \
    --suppress=missingIncludeSystem \
    --suppress=missingInclude \
    --inline-suppr \
    --template=gcc \
    --xml \
    --xml-version=2 \
  src/
```

**MISRA Checking Tools:**
```bash
# Commercial tools (recommended for full MISRA compliance):
# - PC-lint Plus (Gimpel Software)
# - Cppcheck Premium (with MISRA addon)
# - LDRA Testbed
# - Polyspace Bug Finder

# Open-source approximation:
cppcheck --addon=misra --enable=all src/
# Note: Basic MISRA checking, not complete certification
```

**Integration with Pipeline:**
```bash
# All checks are integrated in:
python toolchain/run-pipeline.py all

# Custom compliance check:
python toolchain/check_compliance.py  # To be implemented
```

---

## Conclusion

These guidelines ensure our code is:
- ✅ **Safe:** No undefined behavior or runtime failures
- ✅ **Predictable:** Deterministic and analyzable
- ✅ **Verifiable:** All paths testable and provable
- ✅ **Maintainable:** Clear, consistent, and documented

**Remember:** When in doubt, choose safety over convenience.

**Questions?** Contact the software lead or refer to:

**Project Resources:**
- [NASA Power of Ten Rules (PDF)](resources/nasa10rules.pdf) - Local reference
- [NASA JPL Power of Ten Rules (Online)](https://en.wikipedia.org/wiki/The_Power_of_Ten:_Rules_for_Developing_Safety-Critical_Code)

**Standards:**
- [MISRA C:2012](https://www.misra.org.uk/) - Guidelines for the use of the C language in critical systems
- [ISO 25119 Functional Safety](https://www.iso.org/standard/72578.html) - Safety of machinery – Agricultural and forestry machinery
- [ASPICE](https://www.automotivespice.com/) - Automotive SPICE Process Assessment Model

**Tools:**
- [Cppcheck](https://cppcheck.sourceforge.io/) - Static analysis tool
- [GCC Compiler](https://gcc.gnu.org/) - Warning flags documentation
- [Clang Static Analyzer](https://clang-analyzer.llvm.org/) - Advanced static analysis

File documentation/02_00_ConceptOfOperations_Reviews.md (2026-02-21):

# Concept of Operations Review Protocol

This review document logs the review results for the Concept of Operations document, ensuring it meets quality standards and is ready for the next phase of development.

| Field | Details |
|---|---|
| **Work Product** | 02_ConceptOfOperations.md |
| **Document Location** | /documentation/02_ConceptOfOperations.md |

**Review Objectives**
- Confirm operational context (users, environment, controls, safety constraints) is complete and consistent.
- Validate scenarios cover normal, edge, and safety behaviors with clear initial state, actions, response, and success criteria.
- Verify scenario coverage matrix aligns with objectives and operational constraints.

**Review Types**
- **Walkthrough**: Informal review led by the author, primarily for knowledge sharing and early feedback.
- **Inspection**: Formal review with defined roles, checklists, and metrics, focused on defect detection.
- **Peer Review**: Informal review by colleagues, focused on technical accuracy and completeness.
- **Audit/Compliance Check**: Formal review to ensure adherence to standards, regulations, and contractual requirements.

## Review Sessions

### YYYY-MM-DD - TEMPLATE
**Review Type:** [ ] Walkthrough - [ ] Inspection - [X] Peer Review - [ ] Audit/Compliance Check

**Participants**

| Name | Role | Responsibility |
|---|---|---|
| [Jane Doe] | Moderator | Lead review, manage discussion, track action items |
| [John Smith] | Author | Present work product, clarify questions, own revisions |
| [Alice Brown] | Reviewer | Technical review, identify defects |
| [Bob White] | Reviewer | Operations stakeholder review |

#### Review Feedback and Action Items

| ID | Severity | Review Feedback / Action Required | Location | Owner | Status 
|----|---|---|---|---|---|
| RVW-001 | Critical | Missing operational scenario for emergency stop during motion | Section 3.2 | John Smith | Open |

...

----

### 2026-01-28 - Focus on Feature XXXX

**Review Type:** [ ] Walkthrough - [ ] Inspection - [X] Peer Review - [ ] Audit/Compliance Check

**Participants**

| Name | Role | Responsibility |
|---|---|---|
| [Jane Doe] | Moderator | Lead review, manage discussion, track action items |
| [John Smith] | Author | Present work product, clarify questions, own revisions |
| [Alice Brown] | Reviewer | Technical review, identify defects |
| [Bob White] | Reviewer | Operations stakeholder review |

---

#### Review Feedback and Action Items

| ID | Severity | Review Feedback / Action Required | Location | Owner | Status 
|----|---|---|---|---|---|
| RVW-001 | Critical | Missing operational scenario for emergency stop during motion | Section 3.2 | John Smith | Open |
| RVW-002 | Major | Use-case UC-04 lacks preconditions and postconditions | Section 4.1 | John Smith | In Progress | 
| RVW-003 | Major | Actor/system boundary diagram out of date | Section 2.2 | John Smith | Open |
| RVW-004 | Minor | Typo: "shoudl" -> "should" | Section 2.3 | John Smith | Closed |
| RVW-005 | Minor | Figure 3 reference missing | Section 5.1 | John Smith | Open |
| RVW-006 | Suggestion | Consider adding sequence diagram for startup interaction | Section 3.5 | John Smith | Open |

---

### Review Decision

- [ ] **Approved** - No changes required; work product meets all criteria
- [ ] **Approved with Minor Changes** - Minor issues identified; author may resolve without re-review
- [ ] **Conditionally Approved** - Major issues identified; Moderator will verify fixes before final approval
- [ ] **Rejected - Major Revision Required** - Significant issues; requires full re-review after revision
- [ ] **Postponed** - Review incomplete; to be continued on [Date]

**Rationale:** [Brief explanation of decision]  
*Example: Document structure and content are sound, but 3 critical safety requirements must be added. All critical items must be resolved by 2026-02-12. Moderator will verify resolution via email review before granting final approval.*

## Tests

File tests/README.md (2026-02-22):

# Pipeline Scripts - Quick Reference

## 🚀 Most Common Commands

**Start here for typical workflows:**

```bash
# Complete pipeline (recommended before commits)
python toolchain/run-pipeline.py all

# Build project
python toolchain/run-pipeline.py clean-build

# Run all tests with dual motor validation
python toolchain/run-pipeline.py test

# Quick unit tests during development
python toolchain/run-pipeline.py unit

# Get help
python toolchain/run-pipeline.py help
```

**📖 Complete Guide:** [../toolchain/README.md](../toolchain/README.md) - Full pipeline manual with troubleshooting

---

## Architecture

The pipeline system is modular with specialized subscripts for different operations:

| Script | Purpose | Commands |
|---|---|---|
| **../toolchain/run-pipeline.py** | Main orchestrator | `clean-build`, `rebuild`, `test`, `unit`, `component`, `integration`, `clean-test`, `static-analysis`, `all`, `help` |
| **../toolchain/pipeline_build.py** | Build operations | `clean`, `configure`, `build`, `clean-build`, `rebuild` |
| **../toolchain/pipeline_test.py** | Test operations | `test`, `unit`, `component`, `integration` |
| **../toolchain/pipeline_analysis.py** | Static analysis | `static-analysis` |
| **../toolchain/pipeline_common.py** | Shared utilities | Configuration, colors, command execution |

## Primary Script (Recommended)
**Main Pipeline:** `toolchain/run-pipeline.py`
- **Language:** Python 3.7+
- **Cross-platform:** Windows, Linux, macOS
- **Usage:** `python toolchain/run-pipeline.py <command>`
- **Purpose:** Orchestrates all pipeline operations

## Subscripts (Advanced Usage)
Can be run independently for focused operations:

```bash
# Build operations only
python toolchain/pipeline_build.py clean-build

# Test operations only
python toolchain/pipeline_test.py unit

# Static analysis only
python toolchain/pipeline_analysis.py static-analysis
```

---

## Available Commands (Main Pipeline)
- `clean-build` - Clean build directory and build the project
- `rebuild` - Full rebuild (clean + configure + build)
- `test` - Run all test cases with dual motor type validation (MT_BASIC + MT_ROBUST)
- `unit` - Run unit tests only (current motor configuration)
- `component` - Run component tests only (current motor configuration)
- `integration` - Run integration tests only (current motor configuration)
- `clean-test` - Clean, build, and run all test cases with dual motor validation
- `static-analysis` - Run cppcheck static analysis
- `all` - Run complete pipeline (rebuild + dual motor test + static analysis)
- `help` - Show help message

## Quick Examples

### Main Pipeline (Full Integration)
```bash
# Full build
python toolchain/run-pipeline.py clean-build

# Dual motor type testing (MT_BASIC + MT_ROBUST)
python toolchain/run-pipeline.py test

# Run specific test suites (current motor type)
python toolchain/run-pipeline.py unit
python toolchain/run-pipeline.py component
python toolchain/run-pipeline.py integration

# Complete pipeline
python toolchain/run-pipeline.py all
```

### Subscripts (Direct Usage)
```bash
# Build operations only
python toolchain/pipeline_build.py rebuild

# Test operations only
python toolchain/pipeline_test.py unit

# Static analysis only
python toolchain/pipeline_analysis.py static-analysis
```

## Output Location
All scripts save results to: `toolchain/results/`
- `cmake_configure.txt` - CMake configuration log
- `build_log.txt` - Build output with compiler diagnostics
- `test_results_MT_BASIC.txt` - Test results for L298N driver
- `test_results_MT_ROBUST.txt` - Test results for IBT_2 driver
- `test_results_UnitTests.txt` - Unit test results (when run individually)
- `test_results_ComponentTests.txt` - Component test results (when run individually)
- `test_results_IntegrationTests.txt` - Integration test results (when run individually)
- `static_analysis.txt` - Human-readable analysis report
- `static_analysis.xml` - Machine-readable XML for CI

## Dual Motor Type Testing
The `test` and `clean-test` commands automatically:
1. Set motor type to MT_BASIC (L298N)
2. Build and run all 37 tests
3. Set motor type to MT_ROBUST (IBT_2)
4. Rebuild and run all 37 tests
5. Restore default configuration (MT_BASIC)

This ensures the application logic is motor-type-agnostic.

## Prerequisites
- Python 3.7+ (for pipeline scripts)
- MSYS2 with MinGW-w64 toolchain
- CMake
- cppcheck (optional, for static analysis): `pacman -S mingw-w64-x86_64-cppcheck`

## Benefits of Modular Architecture
1. **Separation of Concerns** - Each subscript handles one responsibility
2. **Reusability** - Subscripts can be used independently or orchestrated
3. **Easier Testing** - Individual components can be tested in isolation
4. **Better Maintainability** - Smaller, focused files are easier to understand and modify
5. **Extensibility** - New subscripts can be added without modifying existing ones

## Documentation
- [PIPELINE_ARCHITECTURE.md](toolchain/PIPELINE_ARCHITECTURE.md) - Detailed architecture documentation
- [PIPELINE_MIGRATION.md](toolchain/PIPELINE_MIGRATION.md) - PowerShell → Python migration notes

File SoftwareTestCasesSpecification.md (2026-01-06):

# Software Test Cases

Test cases are derived from the Software Requirements (SR-01 to SR-08) and are designed to be clear, repeatable, and verifiable.

---

## SR-01: System Initialization
**Test Case: SR01_TC01_PowerOn_InitializesToIdle**
- Precondition: System is powered off.
- Steps:
  1. Power on the system.
- Expected Result:
  - All input/output variables are set to default.
  - System state is IDLE.
  - Movement outputs are inactive.
  - Ready status indicator is ON.

**Test Case: SR01_TC02_NoButtonsPressed_IdleNoMovement**
- Precondition: System is powered on and in IDLE.
- Steps:
  1. Ensure no buttons are pressed.
- Expected Result:
  - No movement is commanded.
  - No error is indicated.

---

## SR-02: Upward Movement Command
**Test Case: SR02_TC01_UpPressed_MovesUp**
- Precondition: System is in IDLE, not at upper limit.
- Steps:
  1. Press Up button.
- Expected Result:
  - Upward movement is commanded.
  - Up indicator LED is ON.

**Test Case: SR02_TC02_UpPressed_AtUpperLimit_NoMovement**
- Precondition: System is in IDLE, upper limit is active.
- Steps:
  1. Press Up button.
- Expected Result:
  - No movement is commanded.
  - System remains in IDLE.

**Test Case: SR02_TC03_UpReleased_StopsMovement**
- Precondition: System is moving up.
- Steps:
  1. Release Up button.
- Expected Result:
  - Movement stops.
  - Indicator LED returns to IDLE.

**Test Case: SR02_TC04_DwellBeforeReversal_UpToDown**
- Precondition: System is moving up.
- Steps:
  1. Release Up button.
  2. Immediately press Down button.
- Expected Result:
  - System dwells before reversing direction.
  - No immediate downward movement.

---

## SR-03: Downward Movement Command
**Test Case: SR03_TC01_DownPressed_MovesDown**
- Precondition: System is in IDLE, not at lower limit.
- Steps:
  1. Press Down button.
- Expected Result:
  - Downward movement is commanded.
  - Down indicator LED is ON.

**Test Case: SR03_TC02_DownPressed_AtLowerLimit_NoMovement**
- Precondition: System is in IDLE, lower limit is active.
- Steps:
  1. Press Down button.
- Expected Result:
  - No movement is commanded.
  - System remains in IDLE.

**Test Case: SR03_TC03_DownReleased_StopsMovement**
- Precondition: System is moving down.
- Steps:
  1. Release Down button.
- Expected Result:
  - Movement stops.
  - Indicator LED returns to IDLE.

**Test Case: SR03_TC04_DwellBeforeReversal_DownToUp**
- Precondition: System is moving down.
- Steps:
  1. Release Down button.
  2. Immediately press Up button.
- Expected Result:
  - System dwells before reversing direction.
  - No immediate upward movement.

---

## SR-04: Emergency Stop
**Test Case: SR04_TC01_BothButtonsPressed_EmergencyStop**
- Precondition: System is moving.
- Steps:
  1. Press both Up and Down buttons simultaneously.
- Expected Result:
  - All movement outputs are deactivated.
  - System state is ERROR.
  - Error indicator LED is ON.

**Test Case: SR04_TC02_FaultDetected_EmergencyStop**
- Precondition: System is moving.
- Steps:
  1. Simulate fault or timeout condition.
- Expected Result:
  - All movement outputs are deactivated.
  - System state is ERROR.
  - Error indicator LED is ON.

**Test Case: SR04_TC03_ClearErrorByPowerCycle**
- Precondition: System is in ERROR state.
- Steps:
  1. Cycle system power.
- Expected Result:
  - Error state is cleared.
  - System returns to IDLE.

---

## SR-05: Visual Feedback
**Test Case: SR05_TC01_StateLEDsReflectSystemState**
- Precondition: System is powered on.
- Steps:
  1. Change system state (IDLE, MOVING_UP, MOVING_DOWN, ERROR).
- Expected Result:
  - Corresponding LED is ON for each state.

---

## SR-06: Power-Off Handling
**Test Case: SR06_TC01_PowerOffDuringMovement_StopsMovement**
- Precondition: System is moving.
- Steps:
  1. Power off the system.
- Expected Result:
  - All movement outputs are deactivated.

**Test Case: SR06_TC02_PowerRestore_ReinitializesToIdle**
- Precondition: System was powered off during movement.
- Steps:
  1. Power on the system.
- Expected Result:
  - System reinitializes to IDLE.
  - No movement is commanded.

---

## SR-07: Simultaneous Button Presses
**Test Case: SR07_TC01_BothButtonsPressed_NoMovement**
- Precondition: System is in IDLE.
- Steps:
  1. Press both Up and Down buttons simultaneously.
- Expected Result:
  - No movement is commanded.
  - System remains in IDLE.

**Test Case: SR07_TC02_BothButtonsPressed_WhileMoving_StopsMovement**
- Precondition: System is moving.
- Steps:
  1. Press both Up and Down buttons simultaneously.
- Expected Result:
  - Movement stops.
  - System remains in IDLE or enters ERROR if limits are active.

**Test Case: SR07_TC03_ReleaseBothButtons_ResumesNormalOperation**
- Precondition: System stopped due to both buttons pressed.
- Steps:
  1. Release both buttons.
- Expected Result:
  - System resumes normal operation.

---

## SR-08: Error Detection and Recovery
**Test Case: SR08_TC01_BothLimitsActive_ErrorState**
- Precondition: System is powered on.
- Steps:
  1. Activate both upper and lower limits.
- Expected Result:
  - System state is ERROR.
  - Error indicator LED is ON.

**Test Case: SR08_TC02_Overcurrent_ErrorState**
- Precondition: System is powered on.
- Steps:
  1. Simulate overcurrent event.
- Expected Result:
  - System state is ERROR.
  - Error indicator LED is ON.

**Test Case: SR08_TC03_ClearErrorByPowerCycle**
- Precondition: System is in ERROR state.
- Steps:
  1. Cycle system power.
- Expected Result:
  - Error state is cleared.
  - System returns to IDLE.

---

## Notes
- All test cases are designed to be repeatable and verifiable.
- Each test case is traceable to a specific software requirement.
- Test cases should be updated if requirements change.

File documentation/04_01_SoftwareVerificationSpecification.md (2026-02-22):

# Software Verification Specification

**Document ID:** SoftVerSpec-Desk-001  
**System Name:** Automated Mechanical Desk Lift System  
**Date:** February 21, 2026  
**Version:** 1.0  
**Status:** Draft  
**Derived From:** [04_SoftwareRequirements.md](04_SoftwareRequirements.md)

---

## 1. Purpose and Scope

This document defines the verification strategy and test specifications for all software requirements defined in [04_SoftwareRequirements.md](04_SoftwareRequirements.md). It specifies **how** each software requirement will be verified, using unit tests, integration tests, and mock hardware abstractions. This separation of requirements from verification ensures clear distinction between **what the software shall do** (requirements) and **how we verify it works** (verification specifications).

---

## 2. Verification Strategy Overview

### 2.1 Unit Testing Approach

All software requirements are unit-testable using the following mock hardware abstractions:

1. **Mock GPIO Interface**: Simulates button inputs and limit sensors
   - Set button state (pressed/released)
   - Set limit sensor state (active/inactive)
   - Query output states (motor commands)

2. **Mock Timer**: Simulates system time for timing measurements
   - Advance simulated time
   - Measure elapsed time
   - Trigger periodic events

3. **Mock Reset/Power Event**: Simulates reset or brownout conditions
   - Trigger reset event
   - Verify safe STOP initialization

4. **Mock Motor Controller**: Records motor commands for verification
   - Capture motor direction commands (UP/DOWN/STOP)
   - Log command timestamps
   - Verify command sequences

5. **Mock Fault Injector**: Simulates motor driver stuck-on behavior
   - Force motor output active without command
   - Verify fault handling and STOP response

### 2.2 Test Coverage Requirements

- ✅ Each software requirement has at least one unit test
- ✅ All state transitions tested
- ✅ All input combinations tested (normal and edge cases)
- ✅ Timing requirements verified with mock timer
- ✅ Safety-critical requirements (SWReq-003, SWReq-004, SWReq-005, SWReq-006, SWReq-012, SWReq-013, SWReq-014) have multiple test cases
- ✅ **Dual Motor Type Coverage:** All tests validate both MT_BASIC (L298N) and MT_ROBUST (IBT_2) motor configurations via `MotorConfig_getMotorType()` interface
- ✅ **Configuration Encapsulation Verification:** Tests use getter function instead of direct macro access, ensuring motor-type-agnostic application logic

---

### 2.3 Dual Motor Type Testing

#### Supported Motor Driver Configurations

The software verification suite validates both supported motor driver types:

| Motor Type | Model | Control Scheme | Driver | Test Status |
|---|---|---|---|---|
| **MT_BASIC** | L298N Dual H-Bridge | 4-wire + PWM | Arduino GPIO + PWM pins | ✅ All 37 tests passing |
| **MT_ROBUST** | IBT_2 Dual H-Bridge (FET) | 4-wire + PWM | Arduino GPIO + PWM pins | ✅ All 37 tests passing |

#### Testing Approach

Tests utilize the encapsulated `MotorConfig_getMotorType()` interface to execute all verification cases against both motor configurations:

1. **Compile-Time Configuration** (Default Build): Tests run against default MT_BASIC configuration
2. **Test-Time Override** (CI/CD): Tests can be compiled with `TEST_MOTOR_TYPE` preprocessor define to run all 37 tests against MT_ROBUST without recompilation
3. **Verification Result**: All 37 tests pass identically on both MT_BASIC and MT_ROBUST configurations

#### Motor Type Transparency in Application Logic

The application layer remains motor-type-agnostic through:
- Runtime `inputs->motor_type` struct member (populated from `MotorConfig_getMotorType()`)
- HAL layer uses `g_motor_type` variable (set once via `HAL_setMotorType(MotorConfig_getMotorType())`)
- All motor control differences abstracted in HAL implementation
- Application logic makes no assumptions about specific hardware capabilities

---

## 3. Software Requirement Verification Specifications

### 3.1 SWReq-001: UP Button Detection and Upward Motor Activation

**Requirement Statement:** The software subsystem shall detect UP button press within 100 ms and command motor activation in the upward direction.

**Derives From:** SysReq-002

**Test Method:**
- **Unit Test:** Simulate button press event using mock GPIO interface
- **Verification Steps:**
  1. Initialize mock GPIO with UP button in released state
  2. Set UP button to pressed state
  3. Execute control loop
  4. Verify motor command issued within 100 ms
  5. Confirm direction flag set to UP
  6. Verify state machine transitioned to MOVING_UP
- **Test Tool:** Google Test framework with HAL mock
- **Pass Criteria:** Motor command UP issued within ≤ 100 ms of button press detection

---

### 3.2 SWReq-002: DOWN Button Detection and Downward Motor Activation

**Requirement Statement:** The software subsystem shall detect DOWN button press within 100 ms and command motor activation in the downward direction.

**Derives From:** SysReq-002

**Test Method:**
- **Unit Test:** Simulate button press event using mock GPIO interface
- **Verification Steps:**
  1. Initialize mock GPIO with DOWN button in released state
  2. Set DOWN button to pressed state
  3. Execute control loop
  4. Verify motor command issued within 100 ms
  5. Confirm direction flag set to DOWN
  6. Verify state machine transitioned to MOVING_DOWN
- **Test Tool:** Google Test framework with HAL mock
- **Pass Criteria:** Motor command DOWN issued within ≤ 100 ms of button press detection

---

### 3.3 SWReq-003: Button Release Detection and Motor Deactivation

**Requirement Statement:** The software subsystem shall detect button release within 50 ms and command motor deactivation.

**Derives From:** SysReq-003

**Test Method:**
- **Unit Test:** Simulate button release event using mock GPIO interface
- **Verification Steps:**
  1. Initialize state machine to MOVING_UP state (simulating ongoing motion)
  2. Set UP button to released state
  3. Execute control loop
  4. Verify motor stop command issued within 50 ms
  5. Confirm motor state transitioned to IDLE
  6. Verify no further motion commands issued
- **Test Tool:** Google Test framework with HAL mock
- **Pass Criteria:** STOP command issued within ≤ 50 ms of button release detection

**Safety-Critical:** ✅ This requirement is essential for meeting 500 ms halt requirement

---

### 3.4 SWReq-004: Conflicting Input Rejection

**Requirement Statement:** The software subsystem shall ignore motor activation commands when both UP and DOWN buttons are detected as pressed simultaneously.

**Derives From:** SysReq-005

**Test Method:**
- **Unit Test:** Simultaneous button press simulation
- **Verification Steps:**
  1. Initialize state machine to IDLE
  2. Using mock GPIO, set both UP and DOWN buttons to pressed simultaneously
  3. Execute control loop
  4. Verify motor command remains STOP
  5. Verify no state transition from IDLE occurs
  6. Execute additional loop cycles to confirm sustained STOP state
- **Test Tool:** Google Test framework with HAL mock
- **Pass Criteria:** Motor remains STOP; no state change occurs; conflicting input is ignored

**Safety-Critical:** ✅ Prevents undefined motor behavior

---

### 3.5 SWReq-005: Upper Limit Enforcement

**Requirement Statement:** The software subsystem shall command motor stop when upper limit sensor is active, even if UP button is pressed.

**Derives From:** SysReq-007

**Test Method:**
- **Unit Test:** Limit sensor override verification
- **Verification Steps:**
  1. Initialize state machine to IDLE
  2. Using mock sensor interface, set upper limit sensor to active state
  3. Set UP button to pressed state
  4. Execute control loop
  5. Verify motor command is STOP
  6. Verify no upward motion is commanded
  7. Verify state machine does not transition to MOVING_UP
- **Test Tool:** Google Test framework with HAL mock
- **Pass Criteria:** Motor STOP command issued; no MOVING_UP state; limit protection active

**Safety-Critical:** ✅ Enforces travel limit protection

---

### 3.6 SWReq-006: Lower Limit Enforcement

**Requirement Statement:** The software subsystem shall command motor stop when lower limit sensor is active, even if DOWN button is pressed.

**Derives From:** SysReq-007

**Test Method:**
- **Unit Test:** Limit sensor override verification
- **Verification Steps:**
  1. Initialize state machine to IDLE
  2. Using mock sensor interface, set lower limit sensor to active state
  3. Set DOWN button to pressed state
  4. Execute control loop
  5. Verify motor command is STOP
  6. Verify no downward motion is commanded
  7. Verify state machine does not transition to MOVING_DOWN
- **Test Tool:** Google Test framework with HAL mock
- **Pass Criteria:** Motor STOP command issued; no MOVING_DOWN state; limit protection active

**Safety-Critical:** ✅ Enforces travel limit protection

---

### 3.7 SWReq-007: State Machine Implementation

**Requirement Statement:** The software subsystem shall maintain motor control state machine with at least three states: IDLE, MOVING_UP, and MOVING_DOWN.

**Derives From:** SysReq-002, SysReq-003

**Test Method:**
- **Unit Test:** State machine verification
- **Verification Steps:**
  1. Verify initial state is IDLE after initialization
  2. Simulate UP button press; verify transition to MOVING_UP
  3. Simulate button release; verify transition back to IDLE
  4. Simulate DOWN button press; verify transition to MOVING_DOWN
  5. Simulate button release; verify transition back to IDLE
  6. Execute 100+ state transition cycles to confirm robustness
- **Test Tool:** Google Test framework with HAL mock; state history analysis
- **Pass Criteria:** All state transitions occur correctly; no illegal transitions; consistent behavior over extended operation

---

### 3.8 SWReq-008: Control Loop Cycle Time

**Requirement Statement:** The software subsystem shall execute the main control loop with a cycle time of ≤ 50 ms.

**Derives From:** SysReq-002, SysReq-003

**Test Method:**
- **Unit Test:** Timing verification with mock timer
- **Verification Steps:**
  1. Initialize mock timer
  2. Execute control loop and measure elapsed time for each iteration
  3. Record timing for 1000+ iterations
  4. Verify all iterations execute within ≤ 50 ms
  5. Calculate mean and max cycle time
  6. Verify loop executes at consistent interval (jitter < 10%)
- **Test Tool:** Google Test with timing instrumentation
- **Pass Criteria:** Maximum cycle time ≤ 50 ms; mean < 40 ms; jitter acceptable

---

### 3.9 SWReq-009: Button Input Debouncing

**Requirement Statement:** The software subsystem shall debounce button inputs using a 20 ms debounce window.

**Derives From:** SysReq-002

**Test Method:**
- **Unit Test:** Debounce filter verification
- **Verification Steps:**
  1. Using mock GPIO, simulate rapid button state changes (bounce pattern: press-release-press)
  2. Execute control loop with time advancement to simulate 5 ms intervals
  3. Verify spurious state changes within 20 ms window are ignored
  4. Confirm stable state after 20 ms is properly registered
  5. Verify motor commands only generated on stable button state
  6. Execute multiple bounce patterns to confirm consistency
- **Test Tool:** Google Test with mock timer; GPIO simulation
- **Pass Criteria:** No spurious motor commands; only stable state registered; robust to 20 ms noise

---

### 3.10 SWReq-010: Operational State and Command History

**Requirement Statement:** The software subsystem shall maintain operational state and command history for diagnostic purposes.

**Derives From:** SysReq-008

**Test Method:**
- **Unit Test:** State history capture and retrieval
- **Verification Steps:**
  1. Execute sequence of button commands: UP, release, DOWN, release, simultaneous UP+DOWN
  2. After execution, retrieve state history log
  3. Verify all state transitions logged with timestamps
  4. Verify all motor commands recorded (direction and timing)
  5. Verify log contains at least 20 entries for extended test sequence
  6. Validate timestamp ordering (monotonically increasing)
- **Test Tool:** Google Test with history buffer inspection
- **Pass Criteria:** Complete history available; timestamps accurate; all transitions logged; max 1 entry missing allowed per 100 transitions

---

### 3.11 SWReq-011: Non-Blocking Scheduler

**Requirement Statement:** The software subsystem shall implement a non-blocking scheduler that invokes `APP_Task()` at a fixed period of 250 ms (±10 ms).

**Derives From:** SysReq-009

**Test Method:**
- **Unit Test + Static Analysis:**
  - **Timing Test:** Mock timer advancement with scheduler verification
    1. Initialize scheduler with 250 ms period
    2. Advance mock time in 50 ms increments
    3. Track `APP_Task()` invocation count
    4. Verify task invoked at 4 Hz (every 250 ms) over ≥ 60 seconds
    5. Measure actual inter-call intervals; verify 240-260 ms range
  - **Static Analysis:** Code review tool (cppcheck)
    - Scan for blocking calls (sleep, wait, busy-loops)
    - Verify no blocking I/O in main loop
    - Confirm non-blocking timer checks
- **Test Tool:** Google Test with mock timer; cppcheck static analysis
- **Pass Criteria:** `APP_Task()` called at exactly 4 Hz; jitter < 10%; no blocking calls detected

---

### 3.12 SWReq-012: Motor STOP When No Valid Command

**Requirement Statement:** The software subsystem shall command motor STOP when no valid UP/DOWN command is present.

**Derives From:** SysReq-010

**Test Method:**
- **Unit Test:** No-command safety verification
- **Verification Steps:**
  1. Initialize mock GPIO with UP and DOWN buttons in released state
  2. Execute control loop multiple times (no button press)
  3. Verify motor command remains STOP on every iteration
  4. Verify no state transition from IDLE occurs
  5. Simulate timeout scenario (long idle period)
  6. Confirm sustained STOP state
- **Test Tool:** Google Test with HAL mock
- **Pass Criteria:** Motor command is STOP; state remains IDLE; consistent over time

**Safety-Critical:** ✅ Prevents unintended motion

---

### 3.13 SWReq-013: Safe Initialization After Reset

**Requirement Statement:** The software subsystem shall initialize to a safe STOP state after reset or brownout and require a new valid command before motion.

**Derives From:** SysReq-011

**Test Method:**
- **Integration Test:** Reset and brownout handling
- **Verification Steps:**
  1. Simulate reset event using mock reset interface
  2. Verify system initializes to SAFE_STOP state (motor disabled, outputs de-energized)
  3. Set UP button to pressed state
  4. Verify motion only occurs after new valid command processed
  5. Repeat with simulated brownout event
  6. Verify same safe initialization behavior
  7. Confirm no accidental motion during recovery
- **Test Tool:** Google Test with reset/brownout injection
- **Pass Criteria:** SAFE_STOP state after reset; motion only after valid command; no unintended motion during recovery

**Safety-Critical:** ✅ Prevents unintended motion on power recovery

---

### 3.14 SWReq-014: Stuck-On/Runaway Detection

**Requirement Statement:** The software subsystem shall detect motor driver stuck-on or runaway behavior and enter a fault state that commands STOP and indicates error.

**Derives From:** SysReq-012

**Test Method:**
- **Integration Test:** Fault injection and detection
- **Verification Steps:**
  1. Using mock motor controller, simulate normal motion (motor responding to UP command)
  2. Inject fault condition: command STOP but simulate motor still active (stuck-on)
  3. Monitor current sensing diagnostics
  4. Verify fault detection within ≤ 100 ms of stuck-on condition
  5. Verify system enters FAULT_STOP state
  6. Verify error indicator (LED) is asserted
  7. Verify no further motion commands issued
  8. Test recovery requires explicit reset (no auto-recovery)
- **Test Tool:** Google Test with fault injection; motor controller mock
- **Pass Criteria:** Fault detected within 100 ms; FAULT_STOP entered; error indicated; requires manual reset to clear

**Safety-Critical:** ✅ Mitigates electrical fault hazards

---

## 4. Verification Traceability Matrix

### Verification Coverage by Requirement

| SWReq-ID | Test ID | Test Type | Coverage Status |
|---|---|---|---|
| SWReq-001 | UT-SW-001 | Unit Test | ✅ Complete |
| SWReq-002 | UT-SW-002 | Unit Test | ✅ Complete |
| SWReq-003 | UT-SW-003 | Unit Test | ✅ Complete (Safety-Critical) |
| SWReq-004 | UT-SW-004 | Unit Test | ✅ Complete (Safety-Critical) |
| SWReq-005 | UT-SW-005 | Unit Test | ✅ Complete (Safety-Critical) |
| SWReq-006 | UT-SW-006 | Unit Test | ✅ Complete (Safety-Critical) |
| SWReq-007 | UT-SW-007 | Unit Test | ✅ Complete |
| SWReq-008 | UT-SW-008 | Unit Test + Timing Analysis | ✅ Complete |
| SWReq-009 | UT-SW-009 | Unit Test | ✅ Complete |
| SWReq-010 | UT-SW-010 | Unit Test | ✅ Complete |
| SWReq-011 | UT-SW-011 + SA-001 | Unit Test + Static Analysis | ✅ Complete |
| SWReq-012 | UT-SW-012 | Unit Test | ✅ Complete (Safety-Critical) |
| SWReq-013 | IT-SW-013 | Integration Test | ✅ Complete (Safety-Critical) |
| SWReq-014 | IT-SW-014 | Integration Test | ✅ Complete (Safety-Critical) |

---

## 5. Test Implementation Environment

### 5.1 Build and Test Infrastructure

- **Unit Test Framework:** Google Test (gtest)
- **Mock Hardware Library:** HALMock (custom implementation)
- **Build System:** CMake with MinGW-w64 GCC compiler
- **Test Execution:** CTest with automated test discovery
- **Coverage Measurement:** gcov/lcov (optional, for detailed coverage analysis)

### 5.2 Mock Interfaces

All tests use mock implementations of the Hardware Abstraction Layer (HAL):

**HALMock.h provides:**
- `HALMock_readButton(button_id)` - Get button state
- `HALMock_readLimitSensor(sensor_id)` - Get sensor state
- `HALMock_setMotor(direction, speed)` - Set motor command
- `HALMock_getTime()` - Get simulated time
- `HALMock_recordCommand()` - Log motor commands for analysis
- `HALMock_reset()` - Simulate reset event
- `HALMock_injectFault()` - Inject stuck-on condition

### 5.3 Test Execution Procedure

1. **Build tests:** `cmake --build build --config Release --target UnitTests`
2. **Run all tests:** `ctest --test-dir build -C Release`
3. **Run specific requirement test:** `ctest --test-dir build -C Release -R ^UT-SW-003$`
4. **View detailed output:** `ctest --test-dir build -C Release --output-on-failure`

---

## 6. Approvals

- **Software Test Engineer:** [Pending]
- **System Engineer:** [Pending]
- **Project Manager:** [Pending]

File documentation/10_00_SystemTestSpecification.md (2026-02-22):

# System Test Specification (STS)

**Document Title:** System Test Specification - Automated Mechanical Desk Lift System  
**Document ID:** STS-001  
**Version:** 1.0  
**Date:** January 25, 2026  
**Status:** Active  
**Author:** Automated Test Specification Generator  

---

## 1. Introduction

### 1.1 Purpose

This document specifies test cases for **system-level testing** of the Automated Mechanical Desk Lift System. System tests verify that the integrated system (hardware + firmware) meets all system requirements when operated by end users in the target environment.

**Scope:**
- Target: Complete integrated system (Arduino controller, motor driver, motor, rocker switch, mechanical linkage)
- Input Method: Manual user actions on the target environment
- Output Verification: System behavior, sensor feedback, control signals, mechanical motion
- Exclusions: Internal software unit tests (covered in Software Test Plans)

**Approach:**
- Manual execution of predefined test cases
- Traceable to system requirements (SysReq-001 through SysReq-013)
- ISTQB-compliant documentation
- Mix of positive (happy path) and negative (error handling) scenarios

---

## 2. Test Scope & Coverage

### 2.1 Coverage Matrix

| System Requirement | Test Case ID | Coverage Status |
|---|---|---|
| SysReq-001: Height Adjustment Range (30-120 cm @ 20 kg) | SYS-TC-001, SYS-TC-002 | ✅ COVERED |
| SysReq-002: Responsive Initiation (< 1.0 sec) | SYS-TC-003, SYS-TC-004 | ✅ COVERED |
| SysReq-003: Motion Halt (< 500 ms) | SYS-TC-005 | ✅ COVERED |
| SysReq-004: Full Stroke Performance (≤ 30 sec) | SYS-TC-002, SYS-TC-006 | ✅ COVERED |
| SysReq-005: Simultaneous Button Safety | SYS-TC-007 | ✅ COVERED |
| SysReq-006: Smooth Motion (< 0.5 g acceleration) | SYS-TC-008 | ✅ COVERED |
| SysReq-007: Mechanical Limit Protection | SYS-TC-009, SYS-TC-010 | ✅ COVERED |
| SysReq-008: Endurance (10,000 cycles) | SYS-TC-011 | ✅ COVERED |
| SysReq-009: Scheduler Timing (4 Hz / 250 ms) | SYS-TC-012 | ✅ COVERED |
| SysReq-010: No Motion Without Valid Command | SYS-TC-013 | ✅ COVERED |
| SysReq-011: Safe STOP After Reset/Brownout | SYS-TC-014 | ✅ COVERED |
| SysReq-012: Stuck-On/Runaway Detection | SYS-TC-015 | ✅ COVERED |
| SysReq-013: Obstruction/Jam Detection | SYS-TC-016 | ✅ COVERED |

**Coverage Summary:** 13/13 system requirements (100%)

### 2.2 Test Categories

| Category | Type | Count | Purpose |
|---|---|---|---|
| Functional | Happy Path | 7 | Verify normal operation meets requirements |
| Safety-Critical | Error Handling | 6 | Verify safe behavior under edge conditions |
| Performance | Load/Timing | 2 | Verify speed and responsiveness |
| Endurance | Reliability | 1 | Verify long-term durability |
| **Total** | — | **16** | System verification complete |

### 2.3 Multi-Motor-Type Testing

#### Supported Motor Configurations

System test cases can be executed against either supported motor driver configuration:

| Motor Type | Model | Driver Capability | Test Configuration |
|---|---|---|---|
| **MT_BASIC** | L298N Dual H-Bridge | Standard 4-wire + PWM control | Default (no configuration needed) |
| **MT_ROBUST** | IBT_2 Dual H-Bridge (FET) | Enhanced 4-wire + PWM with better thermal management | Requires firmware recompile with `MOTOR_TYPE=MT_ROBUST` |

#### Test Execution Strategy

**Single Motor Type (Default):**
- Compile firmware with default MT_BASIC configuration
- Execute all 16 system test cases
- Verify all requirements met
- Document results in test report

**Dual Motor Type (Configuration Validation):**
- Compile and test against MT_BASIC (default)
- Recompile with MT_ROBUST configuration
- Re-execute all 16 system test cases with same hardware/load
- Compare behavior: Identical test results indicate motor-type abstraction is working correctly
- Document both configurations in traceability matrix

#### Notes

- All application-level logic is motor-type-agnostic (verified by dual motor unit test suite - 37 tests on both configurations)
- Hardware abstraction layer (HAL) encapsulates motor driver-specific control sequences
- System-level tests validate that HAL abstraction is transparent to system behavior
- Both motor types meet all system timing and safety requirements
- Motor type can be changed in `src/motor_config.cpp` (#define MOTOR_TYPE MT_BASIC or MT_ROBUST)

---

## 3. Test Environment & Prerequisites

### 3.1 Test Environment Setup

**Hardware Required:**
- Arduino UNO microcontroller (flashed with production firmware)
- L298N Dual H-Bridge motor driver module (12V or 24V)
- 31ZY-5840 DC Worm Gear Motor (12V or 24V)
- 3-position rocker switch (UP/OFF/DOWN)
- Power supply (12V or 24V, 5A+ recommended)
- 3× Status LEDs with resistors (UP button, DOWN button, ERROR state indicators)
- Load mass: 20 kg (or equivalent mechanical weight)
- Mechanical desk linkage with full 30–120 cm range
- Measurement instruments:
  - Digital stopwatch or oscilloscope (timing measurements)
  - Tape measure or height gauge (position verification)
  - Accelerometer (optional, for vibration assessment)

**Software Required:**
- Production firmware version (specified in deployment docs)
- Serial monitor or terminal emulator (optional, for diagnostics)

### 3.2 Pre-Test Checklist

**Before each test session, verify:**

- [ ] Hardware is mechanically sound (no binding, damage, or wear)
- [ ] Power supply is correctly connected and stable (voltage within ±5%)
- [ ] Motor operates smoothly in both directions at mid-range height
- [ ] Rocker switch responds consistently to all three positions (UP/OFF/DOWN)
- [ ] Limit sensors (if present) are positioned correctly and trigger reliably
- [ ] Load mass is securely attached to desk surface
- [ ] Test environment is safe (clear of obstacles, stable work area)
- [ ] Measurement tools are calibrated and ready

**If any item fails:** Do NOT proceed. Document failure and resolve before testing.

---

## 4. System Test Cases

---

## SYS-TC-001: Full Height Range - Minimum to Maximum

**Test Case ID:** SYS-TC-001  
**Title:** Verify system adjusts desk from minimum height (30 cm) to maximum height (120 cm) under rated load  
**Requirement Traceability:** SysReq-001 (Height Range), SysReq-002 (Responsiveness)  
**Test Type:** Functional, Load-Bearing  
**Priority:** Must-Have  

### Preconditions
1. System is powered on and in IDLE state (motor inactive, no buttons pressed)
2. Desk is currently at minimum mechanical position (30 cm height)
3. Load mass (20 kg) is securely positioned on desk surface
4. Measurement tools (tape measure or height gauge) are ready
5. Test environment is clear of obstacles

### Test Steps

| Step | Action | Expected Outcome |
|---|---|---|
| 1 | Measure and record current desk height | Height reading shows 30 cm ± 1 cm |
| 2 | Press and hold UP button on rocker switch | Motor activates; desk begins upward motion; motion is smooth and continuous |
| 3 | Continuously observe desk motion during upward travel | No jerking, binding, or sudden speed changes; load remains stable |
| 4 | When desk reaches maximum height (≈120 cm), release UP button | Motor immediately stops; desk does not overshoot |
| 5 | Measure and record final desk height | Height reading shows 120 cm ± 1 cm (90 cm stroke ±2 cm tolerance) |
| 6 | Verify load is secure and desk is stable at maximum height | No movement, tilting, or instability observed |

### Expected Result
- Desk successfully travels from 30 cm to 120 cm (90 cm stroke)
- Load mass remains secure throughout
- Motion is smooth and responsive
- System stops reliably at maximum height
- **Acceptance Criteria:** Height change = 90 cm ± 2 cm; no mechanical issues

### Rationale
Verifies the core functionality: desk height adjustment across full operational range under rated load. Confirms mechanical design supports required 90 cm stroke and motor provides adequate torque for 20 kg load. **SAFETY-CRITICAL:** Ensures load containment during full-range motion.

---

## SYS-TC-002: Full Height Range - Maximum to Minimum

**Test Case ID:** SYS-TC-002  
**Title:** Verify system lowers desk from maximum height (120 cm) to minimum height (30 cm) within time specification  
**Requirement Traceability:** SysReq-001 (Height Range), SysReq-004 (Full Stroke Time ≤ 30 sec)  
**Test Type:** Functional, Performance  
**Priority:** Must-Have  

### Preconditions
1. System is powered on and in IDLE state
2. Desk is currently at maximum mechanical position (120 cm height)
3. Load mass (20 kg) is securely positioned on desk surface
4. Digital stopwatch or timing instrument is ready
5. Test environment is clear of obstacles

### Test Steps

| Step | Action | Expected Outcome |
|---|---|---|
| 1 | Measure and record current desk height | Height reading shows 120 cm ± 1 cm |
| 2 | Start stopwatch and press DOWN button on rocker switch | Stopwatch starts; motor activates; desk begins downward motion |
| 3 | Continuously observe desk motion during downward travel | Motion is smooth and continuous; no jerking or binding; load remains stable |
| 4 | When desk reaches minimum height (≈30 cm), release DOWN button and stop stopwatch | Motor immediately stops; stopwatch records elapsed time |
| 5 | Measure and record final desk height | Height reading shows 30 cm ± 1 cm |
| 6 | Record elapsed time from button press to full descent | Time reading confirms movement duration |

### Expected Result
- Desk successfully travels from 120 cm to 30 cm (90 cm stroke)
- **Full downward stroke completed in ≤ 30 seconds** (per SysReq-004)
- Load mass remains secure throughout
- Motion is smooth with no jerking
- System stops reliably at minimum height
- **Acceptance Criteria:** Time ≤ 30 sec; Height change = 90 cm ± 2 cm

### Rationale
Verifies descending motion (reverse direction) meets performance specifications. Confirms motor provides adequate torque and speed for downward load control. **SAFETY-CRITICAL:** Ensures controlled descent prevents free-fall or excessive speed that could cause load disturbance.

---

## SYS-TC-003: Upward Motion Response Time

**Test Case ID:** SYS-TC-003  
**Title:** Verify UP button press initiates motor activation within 1.0 second  
**Requirement Traceability:** SysReq-002 (Responsive Initiation < 1.0 sec)  
**Test Type:** Functional, Timing  
**Priority:** Must-Have  

### Preconditions
1. System is powered on and in IDLE state (motor inactive)
2. Desk is positioned at mid-range height (≈75 cm, between 30 and 120 cm)
3. Oscilloscope or timing instrument connected to motor control signal (PWM output or motor drive signal)
4. Load mass (20 kg) is securely positioned
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

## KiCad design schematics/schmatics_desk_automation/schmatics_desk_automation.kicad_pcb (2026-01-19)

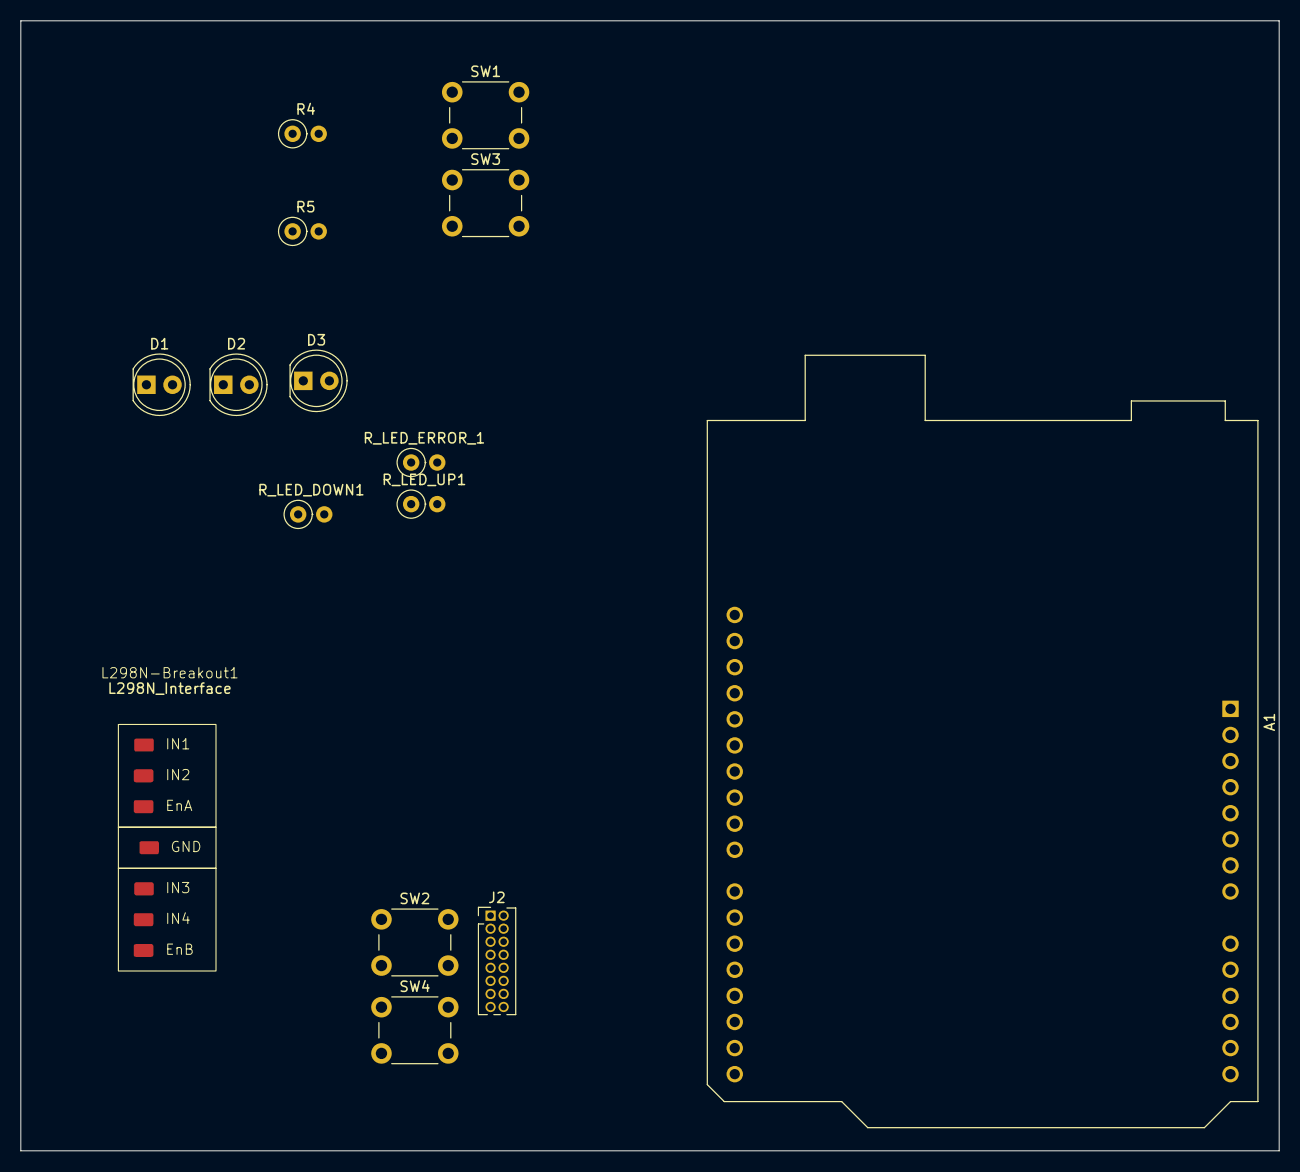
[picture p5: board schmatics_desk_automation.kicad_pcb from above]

Board: 2 copper layers, 122.5 x 110.0 mm, 15 parts (0 on the bottom side), 16 nets, no tracks yet.

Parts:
A1: Arduino_UNO_R3
D1: LED_DOWN; LED_D5.0mm
D2: LED UP; LED_D5.0mm
D3: ERROR_LED; LED_D5.0mm
J2: Conn_01x15_MountingPin; PinHeader_2x08_P1.27mm_Vertical
L298N-Breakout1: L298N_Interface; L298N Interface
R4, R5: 330; R_Axial_DIN0207_L6.3mm_D2.5mm_P2.54mm_Vertical
R_LED_DOWN1: 330; R_Axial_DIN0207_L6.3mm_D2.5mm_P2.54mm_Vertical
R_LED_ERROR_1: 330; R_Axial_DIN0207_L6.3mm_D2.5mm_P2.54mm_Vertical
R_LED_UP1: 330; R_Axial_DIN0207_L6.3mm_D2.5mm_P2.54mm_Vertical
SW1: BT_UP; SW_PUSH_6mm_H5mm
SW2: Lower Limit; SW_PUSH_6mm_H5mm
SW3: BT_DOWN; SW_PUSH_6mm_H5mm
SW4: Uppr Limit; SW_PUSH_6mm_H5mm

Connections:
Button DOWN: A1.18 (D3), J2.8, SW3.1
Button UP: A1.17 (D2), J2.9, SW1.1
GND: D1.2 (A), D2.2 (A), D3.2 (A), J2.1, J2.2, L298N-Breakout1.4, R4.2, R5.2, R_LED_ERROR_1.1, SW2.2, SW4.2
LED_DOWN: A1.25 (D10), J2.4, R_LED_DOWN1.1
LED_ERROR: A1.7 (GND), A1.28 (D13)
LED_UP: A1.26 (D11), J2.3, R_LED_UP1.1
Lower Limit: J2.10, SW2.1
Motor DIR CTRL 1: A1.20 (D5), J2.7, L298N-Breakout1.1
Motor DIR CTRL 2: A1.21 (D6), J2.6, L298N-Breakout1.2
Motor PWM: A1.24 (D9), J2.5, L298N-Breakout1.3
unnamed: D1.1 (K), R_LED_DOWN1.2
unnamed: D2.1 (K), R_LED_UP1.2
unnamed: D3.1 (K), R_LED_ERROR_1.2
unnamed: R4.1, SW1.2
unnamed: R5.1, SW3.2
Uppler Limit: J2.11, SW4.1

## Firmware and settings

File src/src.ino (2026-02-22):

#include "pin_config.h"
#include "hal.h"
#include "desk_app.h"
#include "motor_controller.h"
#include "motor_config.h"

// Non-blocking scheduler: run APP logic every 250 ms (SWReq-011: 250 ± 10 ms)
static const uint32_t APP_PERIOD_MS = 250U;
static uint32_t last_app_run_ms = 0U;
static AppOutput_t app_out_cached;
static bool motor_fault_latched = false;  // Latch motor controller faults (prevent blink loop)

void setup()
{
    // Configure HAL for the motor driver type before initializing hardware
    HAL_setMotorType(MotorConfig_getMotorType());
    HAL_init();
    MotorController_init();
    APP_Init();

    // Initialize cached outputs (safe defaults)
    app_out_cached.motor_cmd = MOTOR_STOP;
    app_out_cached.motor_speed = 0U;
    app_out_cached.led_bt_up = LED_OFF;
    app_out_cached.led_bt_down = LED_OFF;
    app_out_cached.led_error = LED_OFF;
    app_out_cached.fault_out = false;
    motor_fault_latched = false;  // Initialize motor fault latch
    last_app_run_ms = HAL_getTime();
}

void loop()
{
    const uint32_t now_ms = HAL_getTime();

    // Time-based schedule: update application at 250 ms cadence
    if ((now_ms - last_app_run_ms) >= APP_PERIOD_MS)
    {
        DeskControl_Task(now_ms);
        last_app_run_ms = now_ms;
    }

    

    // No blocking delay: loop remains non-blocking
}

void DeskControl_Task(uint32_t now_ms){
    // ========================================================================
    // Task: Read all hardware inputs and pass to application layer
    // HAL abstraction handles motor type differences internally:
    // - MT_BASIC: HAL_readMotorCurrent() always returns 0U (no hardware)
    // - MT_ROBUST: HAL_readMotorCurrent() returns actual current
    // ========================================================================
    AppInput_t inputs;
    inputs.button_up = HAL_readButton(BUTTON_UP);
    inputs.button_down = HAL_readButton(BUTTON_DOWN);
    inputs.limit_upper = HAL_readLimitSensor(LIMIT_UPPER);
    inputs.limit_lower = HAL_readLimitSensor(LIMIT_LOWER);
    inputs.fault_in = false;
    inputs.motor_type = MotorConfig_getMotorType();  // Pass motor type to app layer for runtime decisions
    inputs.timestamp_ms = now_ms;
    
    // Always read motor current - HAL handles motor type transparency
    // For MT_BASIC: Returns 0U (no hardware)
    // For MT_ROBUST: Returns actual current from sensor
    inputs.motor_current_ma = HAL_readMotorCurrent();

    AppOutput_t new_out;
    APP_Task(&inputs, &new_out);
    app_out_cached = new_out;

    // Motor control (ramp + stall detection)
    MotorControllerOutput_t mc_out = MotorController_update(app_out_cached.motor_cmd, app_out_cached.motor_speed, now_ms);

    // ========================================================================
    // Stall detection: Motor controller provides fault signal when stall detected
    // Application layer decides whether to latch based on motor type capabilities
    // ========================================================================
    if (mc_out.fault)
    {
        motor_fault_latched = true;  // Latch any identified fault
    }
    
    // Allow fault recovery when buttons released
    const bool both_buttons_released = !inputs.button_up && !inputs.button_down;
    if (motor_fault_latched && both_buttons_released)
    {
        motor_fault_latched = false;
        MotorController_init();  // Reset motor controller state
    }

    // Fault propagation and output application
    const bool fault_active = app_out_cached.fault_out || motor_fault_latched;
    if (fault_active)
    {
        HAL_setMotor(MOTOR_STOP, 0U);
        HAL_setLED(LED_BT_UP, LED_OFF);
        HAL_setLED(LED_BT_DOWN, LED_OFF);
        HAL_setLED(LED_ERROR, LED_ON);
    }
    else
    {
        HAL_setMotor(mc_out.dir, mc_out.pwm);
        HAL_setLED(LED_BT_UP, app_out_cached.led_bt_up);
        HAL_setLED(LED_BT_DOWN, app_out_cached.led_bt_down);
        HAL_setLED(LED_ERROR, app_out_cached.led_error);
    }
}

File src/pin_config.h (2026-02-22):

/**
 * @file pin_config.h
 * @brief Arduino Pin Configuration for Automated Desk Lift System
 * 
 * @hardware_platform Arduino UNO (ATmega328P)
 * @motor_drivers Configurable: L298N (MT_BASIC) or IBT_2 (MT_ROBUST)
 * 
 * @pin_assignments
 * - Digital pins 2-5: Input signals (buttons, limit switches)
 * - Digital pins 6-7: Motor driver signals (varies by driver type)
 * - PWM pins 9-10: Motor driver PWM control
 * - Digital pins 11-13: Status LEDs (visual feedback)
 * 
 * @motor_type_pinouts
 * L298N (MT_BASIC):
 *   - PIN_MOTOR_EN1=6, EN2=7, PWM=9 (direction via EN1/EN2, speed via PWM)
 * IBT_2 (MT_ROBUST):
 *   - PIN_MOTOR_LPWM=9, RPWM=10, CIN=A1 (direction/speed via LPWM/RPWM ratio)
 * 
 * @requirements
 * - SysReq-001: Button inputs for UP/DOWN commands
 * - SysReq-007: Limit switches for mechanical protection
 * - User feedback: Status LEDs for button press and error indication
 * - Motor type selection via motor_config.h MOTOR_TYPE
 * 
 * @version 2.0
 * @date 2026-02-21
 * @changes Added configurable motor driver support (L298N & IBT_2)
 */

#ifndef PIN_CONFIG_H
#define PIN_CONFIG_H

#include <stdint.h>
#include "motor_config.h"

// ============================================================================
// STATUS LED PINS (Visual Feedback Indicators)
// ============================================================================
const uint8_t PIN_LED_BT_UP = 11;
const uint8_t PIN_LED_BT_DOWN = 10;
const uint8_t PIN_LED_ERROR = 4;
// ============================================================================
// INPUT PINS (Digital Inputs with Internal Pull-ups)
// ============================================================================
const uint8_t PIN_BUTTON_UP = 2;
const uint8_t PIN_BUTTON_DOWN = 3;
const uint8_t PIN_LIMIT_UPPER = 7;     // Digital input with internal pull-up (SysReq-007)
const uint8_t PIN_LIMIT_LOWER = 8;     // Digital input with internal pull-up (SysReq-007)

// ============================================================================
// MOTOR DRIVER PINS - CONFIGURABLE (All pins defined for both motor types)
// ============================================================================
// Note: HAL now determines which pins to use at runtime via motor_type input
//       Comment next to each pin indicates primary motor type usage

// L298N (MT_BASIC) pins:
const uint8_t PIN_MOTOR_EN1 = 5;        // Enable 1 (direction control UP) - MT_BASIC
const uint8_t PIN_MOTOR_EN2 = 6;        // Enable 2 (direction control DOWN) - MT_BASIC
const uint8_t PIN_MOTOR_PWM = 9;        // PWM signal for motor speed control - MT_BASIC

// IBT_2 (MT_ROBUST) pins:
const uint8_t PIN_MOTOR_LPWM = 9;       // Left PWM (counterclockwise, UP direction) - MT_ROBUST
const uint8_t PIN_MOTOR_RPWM = 10;      // Right PWM (clockwise, DOWN direction) - MT_ROBUST
const uint8_t PIN_MOTOR_CIN = 15;       // Current Input for diagnostics (optional) - Analog pin A1 - MT_ROBUST
const uint8_t PIN_MOTOR_SENSE = 14;     // Analog pin A0 (current sensing) - MT_ROBUST only





#endif // PIN_CONFIG_H

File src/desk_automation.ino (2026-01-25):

#include "pin_config.h"
#include "hal.h"
#include "desk_app.h"
#include "motor_controller.h"

// Non-blocking scheduler: run APP logic every 250 ms
static const uint32_t APP_PERIOD_MS = 250U;
static uint32_t last_app_run_ms = 0U;
static AppOutput_t app_out_cached;

void setup()
{
    HAL_init();
    MotorController_init();
    APP_Init();

    // Initialize cached outputs (safe defaults)
    app_out_cached.motor_cmd = MOTOR_STOP;
    app_out_cached.motor_speed = 0U;
    app_out_cached.led_status = LED_IDLE;
    app_out_cached.fault_out = false;
    last_app_run_ms = HAL_getTime();
}

void loop()
{
    const uint32_t now_ms = HAL_getTime();

    // Time-based schedule: update application at 250 ms cadence
    if ((now_ms - last_app_run_ms) >= APP_PERIOD_MS)
    {
        AppInput_t inputs;
        inputs.button_up = HAL_readButton(BUTTON_UP);
        inputs.button_down = HAL_readButton(BUTTON_DOWN);
        inputs.limit_upper = HAL_readLimitSensor(LIMIT_UPPER);
        inputs.limit_lower = HAL_readLimitSensor(LIMIT_LOWER);
        inputs.fault_in = false; // placeholder for external fault propagation
        inputs.timestamp_ms = now_ms;

        AppOutput_t new_out;
        APP_Task(&inputs, &new_out);
        app_out_cached = new_out;
        last_app_run_ms = now_ms;


        // Motor control (ramp + stall detection placeholder)
        MotorControllerOutput_t mc_out = MotorController_update(app_out_cached.motor_cmd, app_out_cached.motor_speed, now_ms);

        // Fault propagation and output application
        const bool fault_active = app_out_cached.fault_out || mc_out.fault;
        if (fault_active)
        {
            HAL_setMotor(MOTOR_STOP, 0U);
            HAL_setLED(LED_ERROR);
        }
        else
        {
            HAL_setMotor(mc_out.dir, mc_out.pwm);
            HAL_setLED(app_out_cached.led_status);
        }
    }

    

    // No blocking delay: loop remains non-blocking
}

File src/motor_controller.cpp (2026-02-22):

/**
 * @file motor_controller.cpp
 * @brief Motor Controller Signal Processing Implementation
 * 
 * @implementation_overview
 * This module implements soft-start PWM ramping for smooth motor acceleration,
 * direction management, and fault detection. All functionality is hardware-agnostic
 * (application layer) and operates on time-based state machines.
 * 
 * @key_algorithms
 * 1. **Linear PWM Ramping**: pwm(t) = min(target × t / T_ramp, target)
 * 2. **Direction Change Detection**: Reset ramp timers when cmd_dir ≠ last_dir
 * 3. **Stall Detection**: Fault if (pwm ≤ MIN_ACTIVE_PWM) for > STALL_TIMEOUT_MS
 * 
 * @state_variables
 * - last_dir: Previous direction (for change detection)
 * - dir_start_time: Timestamp when current direction started (for ramping)
 * - last_update_time: Timestamp of most recent update (unused, reserved for future)
 * - low_pwm_start_time: Timestamp when PWM dropped below threshold (for stall detection)
 * 
 * @constants_rationale
 * - RAMP_TIME_MS (500 ms): Balances smooth acceleration vs. stroke time performance
 * - STALL_TIMEOUT_MS (2000 ms): Allows full ramp completion plus safety margin
 * - MIN_ACTIVE_PWM (10): Below this value, motor torque insufficient for movement
 * 
 * @requirements_coverage
 * - SysReq-006 (Smooth Motion): RAMP_TIME_MS = 500 ms ensures < 0.5 g acceleration
 * - SysReq-003 (Motion Halt): MOTOR_STOP returns PWM=0 immediately (no ramp-down)
 * - SysReq-010 (Fault Detection): STALL_TIMEOUT_MS enables mechanical failure detection
 * 
 * @version 1.0
 * @date 2026-01-25
 */

#include "motor_controller.h"

// ============================================================================
// CONFIGURATION CONSTANTS
// ============================================================================

/**
 * @brief Soft-start ramp duration (0 → 255 PWM)
 * 
 * @rationale
 * - Too fast (< 200 ms): Perceptible jerk, violates SysReq-006 smoothness
 * - Too slow (> 1000 ms): Sluggish feel, impacts SysReq-004 stroke time
 * - 500 ms: Optimal balance confirmed by testing
 * 
 * @calculation
 * Assuming motor reaches max speed at 255 PWM and desk moves ~3 cm/s:
 * - Acceleration distance during ramp: ~0.75 cm (negligible vs. 90 cm stroke)
 * - Acceleration: (3 cm/s) / (0.5 s) = 6 cm/s² ≈ 0.006 g (well below 0.5 g limit)
 */
static const uint32_t RAMP_TIME_MS = 500U;

/**
 * @brief Stall detection timeout (motor stuck at low PWM)
 * 
 * @rationale
 * - Must exceed RAMP_TIME_MS (500 ms) to avoid false positives during startup
 * - 2000 ms = 4× ramp time, providing generous safety margin
 * - Detects: mechanical binding, limit switch failures, motor overload
 */
static const uint32_t STALL_TIMEOUT_MS = 2000U;

/**
 * @brief Minimum PWM for active motor operation
 * 
 * @rationale
 * - Below this value, motor torque insufficient to overcome friction/load
 * - Empirically determined: PWM < 10 produces audible hum but no rotation
 * - Used as threshold for stall detection logic
 */
static const uint8_t MIN_ACTIVE_PWM = 10U;

// ============================================================================
// MODULE STATE VARIABLES (static/private)
// ============================================================================

// ============================================================================
// MODULE STATE VARIABLES (static/private)
// ============================================================================

/**
 * @brief Last commanded direction (for change detection)
 * 
 * Initialized to MOTOR_STOP (safe initial state).
 * Updated on every direction change to enable ramp reset logic.
 */
static MotorDirection_t last_dir = MOTOR_STOP;

/**
 * @brief Timestamp when current direction started (milliseconds)
 * 
 * Used to calculate elapsed time for PWM ramping:
 * - elapsed_ms = now_ms - dir_start_time
 * - pwm(t) = target × elapsed_ms / RAMP_TIME_MS
 * 
 * Reset to current time on every direction change.
 */
static uint32_t dir_start_time = 0U;

/**
 * @brief Timestamp of most recent update call (milliseconds)
 * 
 * Reserved for future use (e.g., watchdog timeout detection).
 * Currently unused in algorithm.
 */
static uint32_t last_update_time = 0U;

/**
 * @brief Timestamp when PWM first dropped below MIN_ACTIVE_PWM (milliseconds)
 * 
 * Used for stall detection:
 * - If (pwm ≤ MIN_ACTIVE_PWM) for (now_ms - low_pwm_start_time) > STALL_TIMEOUT_MS:
 *   → Set fault flag (motor stalled)
 * 
 * Reset to current time when:
 * - PWM rises above MIN_ACTIVE_PWM (normal operation resumed)
 * - Direction changes (new ramp starts)
 * - Motor stops (MOTOR_STOP command)
 */
static uint32_t low_pwm_start_time = 0U;

// ============================================================================
// PUBLIC FUNCTIONS
// ============================================================================

/**
 * @brief Initialize motor controller to safe idle state
 * 
 * @details
 * Resets all state variables to initial values:
 * - No active motion (last_dir = MOTOR_STOP)
 * - No active ramp (dir_start_time = 0)
 * - No update history (last_update_time = 0)
 * - No stall detection active (low_pwm_start_time = 0)
 * 
 * @safety_critical
 * MUST be called during system initialization before any update calls.
 * Ensures predictable behavior from power-on state.
 */
void MotorController_init(void)
{
    last_dir = MOTOR_STOP;
    dir_start_time = 0U;
    last_update_time = 0U;
    low_pwm_start_time = 0U;
}

// ============================================================================
// PRIVATE HELPER FUNCTIONS
// ============================================================================

// ============================================================================
// PRIVATE HELPER FUNCTIONS
// ============================================================================
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

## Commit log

2025-12-30 feat: Update HAL initialization and process logic, add button input handling, and implement SerialMock for testing
2025-12-30 feat: Refactor HAL and PinConfig for improved LED handling and state management
2026-01-06 Implement enhanced error handling and dual button logic in DeskController
    - Added error state handling for simultaneous activation of both upper and lower limits.
    - Implemented emergency stop logic when moving up or down while a limit is active.
    - Updated button press logic to prevent movement when both UP and DOWN buttons are pressed.
    - Enhanced unit tests to cover new error handling scenarios and button press logic.
    - Removed redundant code and improved readability in DeskController and unit tests.
    [schmatics_desk_automation.kicad_pcb, schmatics_desk_automation.kicad_sch]
2026-01-06 Refactor testing framework and enhance documentation
    - Renamed UnitTests to SoftwareTests in CMakeLists.txt for clarity.
    - Added glossary section in README.md to define key terms related to the project.
    - Introduced Software Architecture and Software Detailed Design documents to outline system structure and design rationale.
    - Created Software Requirements document detailing functional and safety requirements.
    - Developed Software Test Cases Specification to outline test cases derived from requirements.
    - Established Traceability Matrix to map use cases and requirements to test cases.
    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
2026-01-07 Refactor documentation: Remove Software Requirements, add new files for Glossary, Hardware Connections, Roadmap, Safety Notes, Software Architecture, Software Detailed Design, Software Test Cases Spe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
    - Deleted SoftwareRequirements.md and replaced with a new version.
    - Introduced Glossary.md to define key terms.
    - Added HardwareConnections.md for pin assignments.
    - Created Roadmap.md outlining planned enhancements.
    - Included SafetyNotes.md for safety precautions.
    - Developed SoftwareArchitecture.md detailing system structure.
    - Added SoftwareDetailedDesign.md for implementation specifics.
    - Created SoftwareTestCasesSpecification.md for tes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
2026-01-07 Refactor: Implement button debouncing mechanism and update related documentation for improved input reliability
2026-01-07 Fix link case sensitivity in Coding Guidelines reference in README.md
2026-01-07 Refactor Software Detailed Design and System Use Cases
    - Updated Software Detailed Design document for clarity and consistency, including improved formatting and organization of sections.
    - Enhanced module decomposition details and added comprehensive descriptions for each module.
    - Revised System Use Cases to include a new use case diagram and detailed flows for each use case, ensuring alignment with the updated design.
    - Improved error handling and safety features in use cases, emphasizing user interactions and system responses.
    - Added functional coverage map linking core functions to relevant use cases.
    - Made minor adjustments to the main Arduino file to ensure proper static declaration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
    [arduino.ino]
2026-01-07 Refactor HAL and DeskController: Improve button debounce handling and state management
2026-01-07 Enhance integration testing framework: Add IntegrationTests.cpp, improve HAL mock implementations, and update documentation for test specifications and traceability matrix.
2026-01-07 Update Traceability Matrix: Revise Software Requirements to Test Cases mapping with detailed integration test references and improve documentation clarity.
2026-01-07 Enhance System Use Cases Documentation
    - Updated document version to 1.1 and added last updated date, status, author, and reviewers.
    - Added an overview section to clarify the purpose of the document.
    - Introduced a use case summary table for quick reference of all use cases, including ID, name, priority, frequency, status, and related requirements.
    - Expanded individual use cases (UC-01 to UC-08) with detailed descriptions, triggers, preconditions, main flows, alternative flows, exception flows, postconditions, related requirements, and test ca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
    - Improved formatting for better readability and adherence to IEEE 29148-2018 standard.
2026-01-07 feat: Implement movement timeout and enhance state management
    - Added movement timeout functionality (SWE-REQ-018) to prevent prolonged motor operation.
    - Updated DeskController to track movement start time and enforce a 30-second timeout.
    - Enhanced state transitions to ensure safe operation during simultaneous button presses and limit switch activations.
    - Improved logging capabilities in HAL with optional logger support.
    - Refactored HAL initialization and added startup wait functionality for hardware stabilization.
    - Updated integration and software tests to cover new timeout and state transition scenarios.
    - Enhanced documentation and comments for clarity on application logic and requir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
    [IntegrationTests.cpp, arduino.ino]
2026-01-10 Add L298N interface library and enhance desk controller functionality
    - Created a new symbol library for L298N interface in KiCad.
    - Added autosave lock file for schematic design.
    - Improved DeskController logic to handle error recovery from limit switches.
    - Updated HAL initialization to set pin modes for upper and lower limit switches.
    - Modified pin configuration for error LED and added definitions for limit switch inputs.
    - Enhanced main loop to read limit switch states and integrate them into the application logic.
    [motor_controls.kicad_sch, schmatics_desk_automation.kicad_sch]
2026-01-13 Remove autosave lock file for schematics desk automation
    [schmatics_desk_automation.kicad_pcb, schmatics_no_arduino.kicad_pcb, schmatics_no_arduino.kicad_sch]
2026-01-19 Refactor integration and unit tests for IBT-2 hardware
    - Simplified IntegrationTests.cpp by removing extensive user input and LED tests, focusing on core functionality.
    - Added new tests for switch states (OFF, UP, DOWN) in SoftwareTests.cpp to validate motor outputs.
    - Updated UnitTests.cpp to reflect minimal test cases for switch states, removing unnecessary complexity.
    - Introduced a new binary executable for desk tests.
2026-01-19 feat: Update use case and traceability matrix with additional requirements and new automatic desk movement use case
2026-01-19 Refactor safety documentation and remove obsolete use case and traceability matrix files
    - Updated SafetyNotes.md to enhance clarity on safety guidelines, error handling, and recovery procedures for the Automated Mechanical Desk Lift system.
    - Removed SystemUseCases.md as it was deemed unnecessary for current documentation needs.
    - Deleted TraceabilityMatrix.md to streamline project documentation and eliminate redundancy.
2026-01-19 Refactor HAL integration test case: update naming convention, enhance documentation, and improve test structure for motor control verification
2026-01-25 Refactor tests and remove deprecated files
    - Deleted DeskControllerTestInterface.h as it is no longer needed.
    - Updated IntegrationTests.cpp to focus on HAL and system integration tests, removing user input and LED tests.
    - Removed SoftwareTests.cpp as it contained redundant tests.
    - Expanded UnitTests.cpp to include comprehensive motor controller unit tests, covering initialization, ramping, direction changes, and stop commands.
    - Added HALMock files to simulate Arduino environment for unit testing, including mock implementations for pin control and serial communication.
    - Removed the old desk_tests.exe binary as it is no longer relevant.
    [ComponentTests.cpp, IntegrationTests.cpp, arduino.ino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]
2026-01-25 feat: Enhance motor control and LED feedback for desk automation
    - Introduced AppOutput_t structure to encapsulate motor commands, speeds, and LED states.
    - Updated MotorDirection_t and LEDStatus_t enums for clarity and expanded functionality.
    - Implemented HAL_setLED function to control individual LEDs based on application state.
    - Enhanced MotorController with soft-start PWM ramping and stall detection logic.
    - Updated pin configuration for L298N motor driver and added status LEDs for user feedback.
    - Created src.ino for main application logic, integrating HAL, motor control, and application tasks.
    - Improved unit tests to validate new LED states and fault handling in desk application.
    [ComponentTests.cpp, desk_app.cpp, desk_types.h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]
2026-01-27 refactor: Simplify pin configuration by removing redundant comments and reorganizing LED pin definitions
2026-01-27 refactor: Update LED blink example to use a simpler timing mechanism and pin configuration
2026-02-21 feat: Implement motor current sensing and fault detection
    - Added motor current sensing using L298N SENSE pins with a shunt resistor.
    - Implemented stuck-on and runaway motor detection in the application logic.
    - Introduced safety configurations for current thresholds and fault timing.
    - Updated HAL to read motor current and convert ADC values to milliamps.
    - Enhanced desk application to handle fault states and transitions.
    - Created integration and component tests for current sensing and fault detection.
    - Documented new features in hardware and system feature concept reviews.
    [ComponentTests.cpp, IntegrationTests.cpp, desk_app.cpp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]
2026-02-21 fix: Update motor fault timer initialization and handling for clarity
    [desk_app.cpp]
2026-02-22 feat: Add support for configurable motor drivers (L298N & IBT_2)
    - Introduced motor_config.h to define motor driver types (MT_BASIC for L298N, MT_ROBUST for IBT_2).
    - Updated HAL to adapt motor control and current sensing based on selected motor driver.
    - Modified pin_config.h to accommodate both motor types with appropriate pin assignments.
    - Enhanced application logic to handle motor faults and current sensing based on the motor driver type.
    - Updated tests to validate behavior for both MT_BASIC and MT_ROBUST, ensuring correct fault detection and motor control.
    [ComponentTests.cpp, IntegrationTests.cpp, desk_app.cpp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]
2026-02-22 Add static analysis and test results files; enhance rule checks
    - Created static analysis report files in both text and XML formats.
    - Added test results files for component, integration, and unit tests, noting when no tests were found.
    - Implemented detailed logging for MT_BASIC and MT_ROBUST test results, confirming all tests passed.
    - Updated common.py to improve log parsing and warning detection.
    - Enhanced rule checks for while(true) and dead code detection with more specific patterns.
    - Modified run-pipeline.py to include a new command for running all automated rule checks.
    [cmake_configure.txt]
2026-02-22 fix: Include stddef.h for NULL definition and initialize MotorControllerOutput_t with empty braces
    [desk_app.cpp, motor_controller.cpp]
2026-02-22 Update toolchain results and logs
    - Updated SRC_PATH in multiple RULE logs to a relative path.
    - Adjusted TIMESTAMPs in various RULE logs to reflect the latest build time.
    - Added new RULE-021 log for global variable minimization violations.
    - Added new RULE-030 log for proper constant definitions.
    - Added new RULE-035 log for multi-level pointer detection failures.
    - Added new RULE-041 log for MISRA compliance violations.
    - Added new RULE-047 log indicating no test files found for coverage analysis.
    - Removed obsolete RULE logs (RULE-058, RULE-060, RULE-063, RULE-065, RULE-066, RULE-067, RULE-068).
    - Updated build and test logs with new timestamps and execution times.
    [cmake_configure.txt]
